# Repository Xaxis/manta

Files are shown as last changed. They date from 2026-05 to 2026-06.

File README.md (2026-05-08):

# MANTA

A wingsuit-extension rigid wing. Pilot wears a fitted wingsuit-derivative
harness with an integrated CFRP spine yoke. Arm-aligned spars hinge from
the spine at the shoulders and brace into position as the pilot spreads
to a flight pose. Telescoping tip extensions snap out from the wrists; a
body-mounted TE spar telescopes spanwise from a hub at the lower back.
Deployable rapidly in flight or on the ground.

This is a real flight vehicle program. Read [`BRIEF.md`](BRIEF.md) before
touching anything else.

**Live project site:** <https://manta-ten.vercel.app>

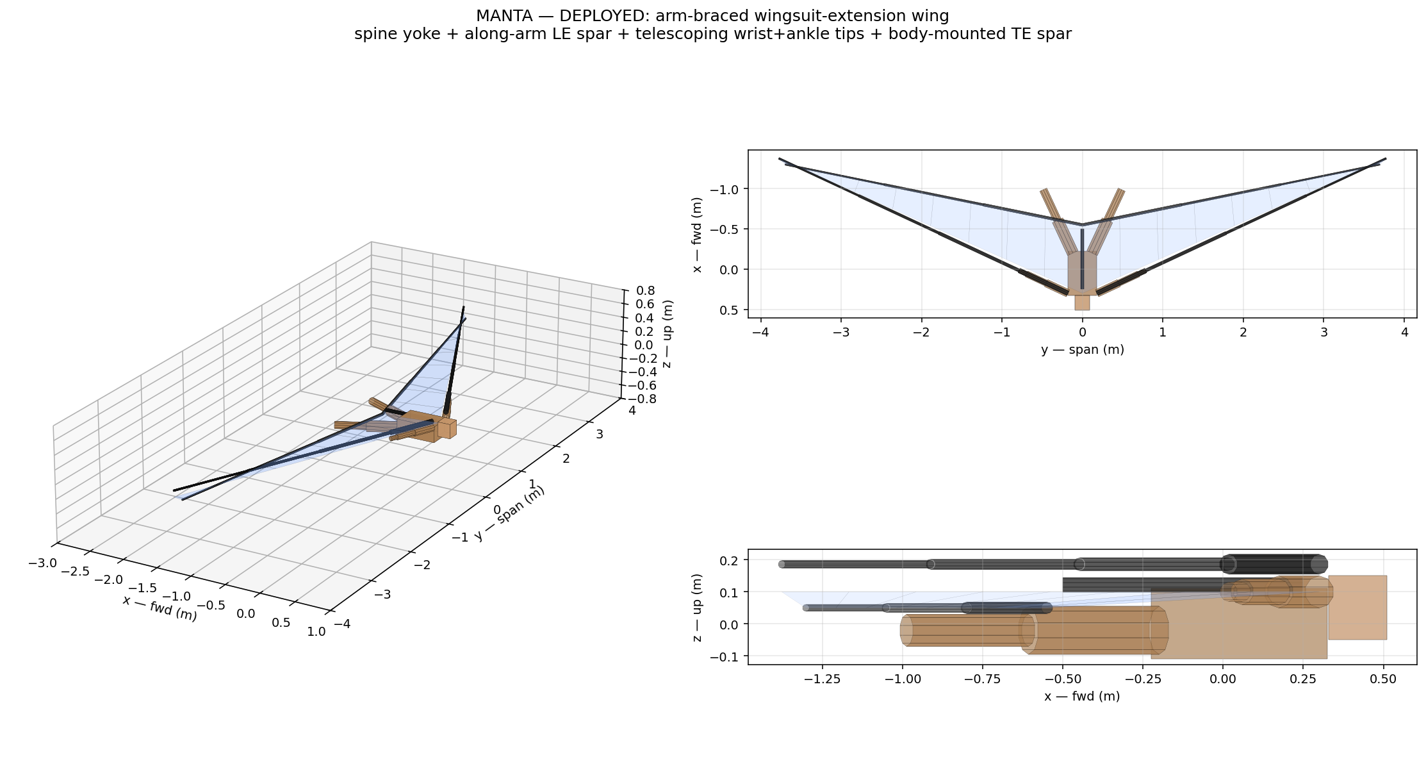
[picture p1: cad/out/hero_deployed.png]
MANTA deployed


## Status

Architecture rebuilt (see [BRIEF v2](BRIEF.md)). The first-cut analyses
across deliverables #1–#6 hold against the corrected architecture; the
wing geometry numbers are independent of how it integrates with the
pilot. CAD and viewer have been rebuilt from scratch around the
arm-braced wingsuit-extension concept.

| BRIEF Deliverable | Doc | Analysis | Tests | Status |
|---|---|---|---|---|
| #1 Aero sizing | [`docs/01`](docs/01-aero-sizing.md) | [`aero/`](analysis/aero/) | 5 ✓ | first-cut |
| #2 Mass budget | [`docs/02`](docs/02-structural-budget.md) | [`struct/mass_budget.py`](analysis/struct/mass_budget.py) | 8 ✓ | first-cut |
| #3 Spar bending | [`docs/02`](docs/02-structural-budget.md) | [`struct/spar_bending.py`](analysis/struct/spar_bending.py) | 8 ✓ | first-cut — load path needs update for arm-braced architecture |
| #4 Deployment sequence | [`docs/03`](docs/03-deployment-sequence.md) | [`deployment/state_machine.py`](analysis/deployment/state_machine.py) | 7 ✓ | first-cut — phases A-B-D added in BRIEF v2 |
| #5 Symmetry budget | [`analysis/deployment/symmetry-budget.md`](analysis/deployment/symmetry-budget.md) | [`deployment/symmetry_budget.py`](analysis/deployment/symmetry_budget.py) | — | first-cut |
| #6 Ground rig spec | [`test/ground/spec.md`](test/ground/spec.md) | — | — | spec drafted — needs update for new kinematics |
| (also) FCS + alpha limiter | [`docs/04`](docs/04-fcs-architecture.md) | [`fcs/`](fcs/) | 7 ✓ | first-cut |
| (also) FMEA | [`safety/fmea.md`](safety/fmea.md) | 11 per-mode files in [`safety/failure-modes/`](safety/failure-modes/) | — | first-cut — pyrotechnic-cutter rows obsolete in BRIEF v2 |
| (also) CAD (corrected) | [`cad/build.py`](cad/build.py) | [`cad/render.py`](cad/render.py) | — | parametric, single source of truth |

> 27 / 27 tests passing. Full suite: `make test`. Site auto-deploys via GitHub Actions on every push touching `site/**`.

## Architecture

Per [`BRIEF.md`](BRIEF.md):

- **Pilot is the fuselage.** Body horizontal in flight, head forward.
- **Spine yoke** (CFRP backbone in the harness) along the back; spar pivots at shoulder + lower-back hub.
- **LE spar** along each arm (shoulder → wrist) with the arm fitted alongside; the spar carries bending load, the arm provides shape and control input.
- **Wrist tip extension** — 3-stage telescoping CFRP from the wrist outward to the wingtip LE.
- **TE spar** — body-mounted spanwise boom from a hub at the lower back, 3-stage telescoping to the wingtip TE. Does not run along the leg (geometric constraint: leg sweep doesn't match TE sweep).
- **Bistable CFRP tape-spring ribs** chordwise between LE and TE spars at multiple span stations.
- **DCF skin** spans LE-to-TE, anchored at body, arms, legs, and tips.
- **Reserve canopy** mounted on the back. After tip-extension retract OR yoke-pivot release, structure folds clear of the reserve cone.
- **Pilot retains wingsuit mode** — if the rigid extensions are fully retracted, the pilot is in a fabric-wingsuit configuration with normal canopy descent capability. That's the architectural fallback.

## Open architecture-amendment findings

1. **V_bg ≈ 16 m/s, not 25 m/s** — wing's natural best-glide is ~16 m/s with the locked planform.
2. **Front spar must grow** to 73 mm OD root, 2.5 mm wall — bending analysis surfaced the original spec failed at 3 g limit. Now relevant to the LE-spar root cross-section.
3. **Active per-side flow modulation** required to close the 10 ms 3-σ symmetry budget.
4. **Architecture is wingsuit-extension, not aircraft-on-back** (BRIEF v2). The prior assumption (separate aircraft on top of a piggyback rig with pyrotechnic spar-root cutters) was wrong; the actual concept is the arm-braced wing. CAD, viewer, and integration are rebuilt around this.

## Reproducibility

```sh
make venv          # one-time setup of .venv
make aero          # planform → Weissinger → trim → glide polar
make struct        # spar bending + mass budget
PYTHONPATH=. .venv/bin/python cad/build.py    # parametric CAD (STL + STEP per part)
PYTHONPATH=. .venv/bin/python cad/render.py   # static iso/top/side hero renders
make test          # full pytest suite
```

Site:

```sh
cd site && bun install && bun run dev    # local preview
cd site && bun run build                  # static build to dist/
```

## Engineering bar

> Would this analysis hold up if a coroner's office asked for it?

If no, it isn't done.

## Where things live

| Path | What's there |
|---|---|
| [`BRIEF.md`](BRIEF.md) | The brief (v2 — wingsuit-extension architecture). |
| [`docs/`](docs/) | Numbered design documents (rationale → aero → structure → deployment → FCS → emergency → test plan → pilot training). |
| [`analysis/`](analysis/) | Quantitative analysis: aero, struct, deployment, flight dynamics. Reproducible via `make`. |
| [`cad/`](cad/) | Single parametric build at `cad/build.py`. Outputs per-part STLs to `cad/out/parts/`. |
| [`fcs/`](fcs/) | Flight control: alpha limiter, SITL simulator, envelope-protection unit tests. |
| [`test/`](test/) | Test article specifications: bench characterization, ground deployment rig, tow article, drop article. |
| [`safety/`](safety/) | FMEA, reserve-parachute compatibility, per-failure-mode write-ups. |
| [`site/`](site/) | Astro + Tailwind + R3F static site. Auto-deploys to manta-ten.vercel.app. |

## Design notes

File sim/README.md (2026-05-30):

# sim — physics + deployment animation pipeline

Two layers, one source of truth for the geometry.

```sh
PYTHONPATH=. .venv/bin/python sim/aero.py              # aero-model closure check
PYTHONPATH=. .venv/bin/python sim/flight_dynamics.py   # trajectory + plot + telemetry
PYTHONPATH=. .venv/bin/python sim/build.py             # MuJoCo kinematics -> animated GLB
PYTHONPATH=. .venv/bin/python sim/build.py --render    # ... + 3 hero stills (Eevee)
```

## 1. Flight physics — `aero.py` + `flight_dynamics.py`

A real six-state longitudinal flight simulation of the whole sequence:
**belly-to-earth freefall → drogue stabilisation → wing deploy → load-limited
pull-out → captured best-glide.**

The aerodynamic coefficients in `aero.py` are derived from the locked planform
(`S = 8.4 m²`, `AR = 6.5`, `e = 0.85`, `CD0 = 0.025`) and are **not** tuned to
hit the BRIEF targets — the targets fall out of the geometry. `aero.py`
asserts the closure on every run:

| Quantity | Model | BRIEF target |
|---|---|---|
| Best-glide speed `V_bg` | **17.0 m/s** | ~16 m/s |
| Max L/D | **13.2** | 10:1 design, 13:1 stretch |
| Stall speed | **12.6 m/s** | < 14 m/s |
| Stowed terminal velocity | **43.9 m/s** | belly freefall ~ |

Coefficients are interpolated stowed→deployed by the deploy progress `p`, so a
single model spans the bluff freefalling body (`p=0`, no lift, vertical
terminal velocity) and the locked wing (`p=1`).

`flight_dynamics.py` integrates the trajectory at 1 ms and closes the pitch
loop with a fly-by-wire longitudinal autopilot (BRIEF #8): a load-factor-limited
flight-path tracker with speed-on-pitch energy regulation and a 12° alpha
limiter. The simulated sequence settles to:

```
V = 17.1 m/s   γ = -4.2°   L/D = 13.7   α = 6.3°   n = 1.0 g
deploy pull-out peak load = 3.1 g   (within the 3 g limit-load spar sizing)
```

Outputs: `out/flight_dynamics.png` (six-panel trace), `out/telemetry.json`
(per-frame series for the web viewer overlay).

## 2. Full mechanical model + deployment animation — `build.py`

`run_simulation()` integrates the deployment **schedule** in MuJoCo (shoulder/
hip yokes spread over Phase A; the wrist + ankle tip booms telescope out over
Phase B). That schedule drives the wing's open fraction.

The vehicle is built from the **resized planform** (BRIEF #5: `S = 6.5 m²`,
`b = 6.3 m`, `AR = 6.1`, `25°` LE sweep, taper `0.4`, `6°` washout — downsized
from 8.4 m²/7.4 m since MANTA lands under reserve) as a **double-surface
cambered wing, tip-to-tip**: an upper deployed skin + a lower wingsuit membrane
meeting at the LE/TE, with the pilot + telescoping spars INSIDE the airfoil — a
ram-air/paraglider-style closed section, continuous across the body and between
the legs.

The pilot is a **fixed-proportion, rigid-size human** (NASA-STD-3000 / ANSUR II
segment lengths) and **never stretches**. Deployment runs forward kinematics
(`_pilot_fk`): the limbs only *rotate* about the shoulder/hip with **constant
bone lengths** (upper arm 0.32 m, forearm 0.27 m, thigh 0.43 m, shank 0.42 m) —
arms angle forward-out toward the LE, legs aft-out forming the **rear/tail**.
The full 7.4 m span beyond the pilot's ~0.76 m wrist reach is provided by the
**3-stage telescoping booms**, not by growing the limbs. Every BRIEF component
is modelled as a named material slot:

| slot | parts |
|---|---|
| `suit` | pilot / harness garment body |
| `cfrp` | spine yoke (box beam), shoulder + hip pivot hubs, LE spar, TE spar, 3-stage telescoping tip booms |
| `skin` | cambered NACA-4412 wing (camber + thickness + washout + billow scallop between ribs) |
| `rib`  | 9 bistable airfoil-profile ribs per side |
| `reserve` | reserve container on the back, above the spine yoke |
| `fcs`  | flight-control bay on the spine |
| `flaperon` | trailing-edge flaperons (deflect down on deploy) |
| `metal` | CO₂ canisters + tip-hub fittings |

The deployable geometry is **one mesh with a fixed topology that is identical on
every frame**; the 60 frames are stored as **morph targets (shape keys)** — a
single `manta.glb` with a real, continuously-interpolated deployment animation
(no opacity crossfades, no per-pose static meshes). Identical-topology morphing
sidesteps skin-weight / bone-roll bookkeeping and guarantees the exact geometry
on every frame, which is what makes the web scrub exact.

## 3. Aero field — surface pressure + streamlines

`build_pressure_object()` and `build_flow_object()` bake an **illustrative**
aerodynamic field onto the deployed wing as two *separate static* GLB objects
(`PRESSURE`, `FLOW`) so they never contaminate the morph mesh's materials:

* **Pressure colormap** — surface Cp on the wing (suction-blue over the leading
  edge, recovering aft), via a thin-airfoil `cp_at()` model **scaled by the real
  Weissinger span-loading** (`analysis/aero/weissinger/out/span_loading.csv` at
  the glide α≈6°).
* **Streamlines** — upwash ahead of the LE → acceleration over the suction peak
  → downwash behind the TE; coloured by local speed `√(1−Cp)`.

This is an **intuition field for the web viewer, NOT a CFD solution** — SU2 /
OpenFOAM is the rigorous follow-up per the BRIEF tool stack. The viewer labels
it as such. The web viewer (`site/src/components/viewer/Viewer.tsx`) plays the
deployment by scrubbing a `THREE.AnimationMixer` clock from the deploy slider,
and its **Flow field** toggle reveals `PRESSURE` + animated `FLOW` streamlines
(a small shader scrolls pulses along each line) over the fully-deployed wing.

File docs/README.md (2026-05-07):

# docs/

Numbered design documents. Read in order.

| # | Document | What it covers |
|---|---|---|
| 00 | [design-rationale](00-design-rationale.md) | Why each locked architecture decision in BRIEF.md was made. The trade studies and rejected alternatives. |
| 01 | [aero-sizing](01-aero-sizing.md) | Planform sizing, airfoil selection, sweep/taper/washout, AVL trim and stability derivatives, L/D verification. |
| 02 | [structural-budget](02-structural-budget.md) | Mass budget, load cases, spar sizing, root-joint design, safety factors. |
| 03 | [deployment-sequence](03-deployment-sequence.md) | Full deployment timeline, sensed handshakes, abort logic. The doc the safety case is built around. |
| 04 | [fcs-architecture](04-fcs-architecture.md) | FCS hardware redundancy, sensor suite, EKF, control laws, envelope protection, mechanical reversion. |
| 05 | [emergency-systems](05-emergency-systems.md) | Spar-root cutters, jettison logic, AAD integration, reserve compatibility, asymmetric-deployment detection. |
| 06 | [test-plan](06-test-plan.md) | Ground rig → tow article → drop article → flight test progression. Gates, instrumentation, success criteria. |

## Conventions

- Every quantitative claim cites its source (analysis file, vendor datasheet, textbook + page).
- Every assumption is called out explicitly, with a justification or a TODO to retire it.
- Every safety-critical claim has a corresponding test in the test plan.
- Diagrams live alongside the doc that references them.
- Treat docs as code — review changes.

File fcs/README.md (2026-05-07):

# fcs/

Flight Control System: firmware, simulation, envelope-protection logic.

**Pairs with:** `docs/04-fcs-architecture.md`, `analysis/flightdynamics/`, and the deployment state machine in `docs/03-deployment-sequence.md`.

## Subdirectories

| Path | Purpose |
|---|---|
| [`firmware/`](firmware/) | PX4 fork (or ArduPilot — pick after architecture review). MANTA-specific modules: deployment state machine, alpha limiter, jettison logic, spar-lock sensor handling. |
| [`sim/`](sim/) | SITL configurations, vehicle model wired to `analysis/flightdynamics/`, scripted mission scenarios for envelope-protection development. |
| [`envelope-protection/`](envelope-protection/) | Standalone development of the alpha limiter and other limiters with unit tests, gain schedules, and HIL fixtures before they land in firmware. |

## Locked from BRIEF

- Redundant Pixhawk-class hardware.
- EKF at 400 Hz.
- Mechanical reversion to direct cable as last-resort backup — the FCS code must not assume it is the only path to the surfaces.
- Alpha limiter is a structural design assumption, treated as required for safe operation.

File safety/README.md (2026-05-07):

# safety/

Safety case artifacts. The bar:

> Would this analysis hold up if a coroner's office asked for it?

If no, it isn't done.

## Contents

| Path | Purpose |
|---|---|
| [`fmea.md`](fmea.md) | Failure mode and effects analysis. Living document — updated as design and test evidence evolves. |
| [`reserve-compat.md`](reserve-compat.md) | Reserve parachute compatibility analysis. The hard-constraint document — the rig must function for canopy flight and landing after wing jettison, and the reserve must deploy clean over the head with no wing-structure occlusion. |
| [`failure-modes/`](failure-modes/) | Per-failure-mode write-ups. Each one: detection, mitigation, response, residual risk, test evidence. |

## Process rules

- Every failure mode listed in `fmea.md` either has a mitigation that closes it to acceptable residual risk, or is a stop-work item until it does.
- Every safety-critical claim cites the test that verifies it — no test, the claim is unverified.
- Failure investigations during test must complete and be reviewed before progression. No "ran it again, it worked."
- Asymmetric deployment is the dominant unrecoverable failure mode (BRIEF). Its file under `failure-modes/` is the one that gets the most attention.

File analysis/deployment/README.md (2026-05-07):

# analysis/deployment/

Deployment dynamics. Pairs with `docs/03-deployment-sequence.md`.

## Tools

- 0-D / 1-D pneumatics for CO2 cartridge → manifold → actuator energy delivery.
- Python ODE models for tape-spring rib snap-through dynamics.
- High-speed video (frame extraction) once the ground rig is built — feeds parameter ID back into the models.

## Expected layout (to be populated)

```
deployment/
├── pneumatics/             # CO2 blowdown, manifold balance, valve opening
├── tape-spring/            # bistable shell snap-through energy + timing
├── timing/                 # composite end-to-end timeline + per-stage budgets
├── symmetry-budget.md      # deliverable #5
├── drogue/                 # ringslot reefed inflation, snatch loads
└── README.md
```

## Critical: symmetry budget (deliverable #5)

`symmetry-budget.md` quantifies left-right deployment timing variance, contributors include (non-exhaustive):

- CO2 cartridge fill mass tolerance and temperature dependence
- Valve opening time-to-flow variance
- Manifold flow-impedance balance
- Spar friction (telescoping stages, with water/ice ingress)
- Tape-spring snap-through dispersion
- Sensor-trigger threshold variance

**Hard gate:** total left-right variance must close to under **10 ms 3-σ** across the operational envelope. If the budget does not close, architecture decision #5 in BRIEF is reopened.

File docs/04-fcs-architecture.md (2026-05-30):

# 04 — FCS Architecture

> **⚠ Resized planform — FCS is now MORE load-bearing.** The wing was downsized
> to **6.5 m² / 6.3 m, AR 6.1, 7° washout** (BRIEF findings #5/#6) and the
> flight-dynamics were re-run. The binding (CG-based) **static margin is ~2.7 %
> MAC** (a ~3 cm aft pilot shift takes it neutral) and **Dutch-roll ζ dropped to
> 0.17** (was 0.29). Consequence: the **alpha-limiter and the artificial yaw
> damper are now MANDATORY flight-safety items**, not optional. `analysis/
> flightdynamics/out/` + `fcs/sim/out/` are regenerated for the new planform.

**Status:** First-cut closed. Limiter prototype, longitudinal dynamics
analysis, and closed-loop characterization are runnable. Outstanding work
is the lateral-directional axis and the actual hardware/firmware build
(PX4 fork or ArduPilot equivalent).

## Locked from BRIEF

- Redundant Pixhawk-class FCS.
- EKF at 400 Hz.
- MEMS IMUs.
- Flaperons (servo-driven, brushless waterproof) on the outer trailing
  edge each side.
- **Alpha limiter is a structural design assumption** — not a feature, an
  invariant the structural sizing depends on.
- Mechanical reversion to direct cable as last-resort backup.

## Why the alpha limiter is load-bearing

Two findings from the upstream analyses converge here:

1. **Static margin is tight.** At design CL the wing has 5.4 % MAC margin
   (top-of-BRIEF-range washout). At higher CL (slow flight, near stall)
   it drops below 4 %. ([`docs/02`](02-structural-budget.md), [`analysis/aero/trim/`](../analysis/aero/trim/))

2. **Pilot motion eats most of the margin.** The pilot is 79 % of the
   vehicle mass and not rigid. A 50 mm head/torso CG shift produces a
   ±3.26 % MAC vehicle-CG shift — comparable to the entire static margin.
   At the trim CG, short-period damping ζ = 0.97 (heavily damped). At a
   50 mm aft pilot shift, the wing goes neutrally stable; at larger
   shifts, divergent. ([`analysis/flightdynamics/longitudinal.py`](../analysis/flightdynamics/longitudinal.py))

The alpha limiter, combined with body-rate damping in the inner loop, is
the only thing that prevents departure during a worst-case posture
perturbation at high CL. Loss of the limiter is a **hazardous failure
mode**, listed in the FMEA.

## Topology

```
                                     ┌──── pitot/static (×2) ────┐
                                     │                            │
                                     │     AoA vane (×1)          │
                                     │     IMU triplex            │
                                     │     spar-lock GPIO (×6)    │
                                     │     skin-tension cells (×4)│
                                     │     drogue load cell       │
                                     │                            ▼
                                     │                       ┌─────────────┐
                                     │                       │ EKF (400Hz) │
                                     │                       └─────┬───────┘
   pilot stick / abort handle        │                              │
   AAD trigger (FCS-bypassed)        │                              ▼
            │                        │      ┌─────────────────────────────────┐
            │                        ├─────►│ Outer loop: trim, glide, alpha  │
            │                        │      │  hold + ALPHA LIMITER           │
            │                        │      └─────────────────┬────────────────┘
            │                        │                         ▼
            │                        │        ┌──────────────────────────────┐
            │                        ├───────►│ Inner loop: pitch-rate,      │
            │                        │        │  roll-rate, yaw-rate damping │
            │                        │        └─────────────┬────────────────┘
            ▼                        │                       ▼
     ┌──────────────────────────┐    │             ┌────────────────────┐
     │ Deployment state machine │────┘             │ Mixer + servo cmd  │
     │ + jettison interface     │                  └─────────┬──────────┘
     └──────────────────────────┘                            ▼
                                                  ┌──────────────────────┐
                                                  │ Flaperon servos (×4) │
                                                  └──────────────────────┘
```

## Hardware redundancy

- **Two Pixhawk-class FCS units** (FCS-A and FCS-B), running cross-checked
  EKFs. Either can fly the vehicle alone; swap is automatic on health failure.
- **Independent power rails** for FCS-A and FCS-B; a third independent rail
  for the mechanical-reversion logic + cutter firing circuit so jettison
  remains possible if both FCS units lose power.
- **Standalone aux IMU** wired to FCS-B (and physically separated from the
  FCS-A IMUs) — provides a third attitude solution for cross-check.
- **AAD signal** wired directly to the cutter firing circuit, bypassing
  both FCS units. (See `safety/failure-modes/aad-fault.md`.)
- **Mechanical reversion**: direct cable from a stick-style pitch input to
  the flaperons. Operable with FCS fully unpowered; pilot reach geometry
  verified in `cad/harness/`.

## Sensor suite

| Sensor | Count | Purpose | Notes |
|---|---|---|---|
| 9-DoF IMU | 3 (FCS-A, FCS-B, aux) | attitude, body rates, accel | Cross-checked via EKF |
| Magnetometer | 2 | heading | Magnetic deviations from skydiving rig metalwork need calibration on every aircraft |
| GNSS | 2 | position, ground speed | Degraded-mode ground speed if pitot fails |
| Pitot-static | 2 | airspeed, altitude rate | Boom location TBD; must avoid wing wake during deploy |
| AoA vane | 1 | direct α | Single-channel; loss → degraded-mode α estimate from trim equation |
| Spar-lock micro | 6 | deployment confirmation | ≤ 1 ms latency requirement (see `docs/03`) |
| Skin tension load cells | 4 | deploy diagnostic | Advisory only — does not gate deployment |
| Drogue load cell | 1 | deployment gate | Cross-checked vs. accel signature |

## Control laws

### Outer loop — alpha limiter (the central piece)

Implementation: [`fcs/envelope_protection/alpha_limiter.py`](../fcs/envelope_protection/alpha_limiter.py).

Limit schedule:

| V (m/s) | α_limit (°) | α_limit, sensor degraded (°) |
|---|---|---|
| 10 | 7.86 | 6.36 |
| 14 | 9.00 | 7.50 |
| 16 (V_bg) | 9.00 | 7.50 |
| 20 (cruise) | 9.00 | 7.50 |
| 25 | 9.00 | 7.50 |
| 30 | 9.00 | 7.50 |
| 35 | 9.50 | 8.00 |
| 40 | 10.00 | 8.50 |

Stall α is 11.5° (analytic polar). Margin 2.5° in the cruise band, +1.5° additional in degraded mode (sensor failure).

Behavior:
- Pilot stick → α_pilot_cmd
- α_cmd = min(α_pilot_cmd, α_limit(V, sensor_state))
- saturated flag → inner loop integrator anti-windup
- degraded flag → α estimate from trim equation: α = α₀ + (1/CL_α) · (m·g)/(½·ρ·V²·S)

Validated by 7 unit tests in [`fcs/envelope_protection/tests/`](../fcs/envelope_protection/tests/).

### Inner loop — pitch / roll / yaw rate damping

PI on α error + Kq on pitch rate (longitudinal). Same structure for the
lateral axes. Anti-windup hooks via the α-saturated flag from the outer
loop. Tunings are placeholders pending high-fidelity 6DOF in SITL.

### Trim hold

Slow (~1 Hz) outer loop adjusts α_cmd to maintain a target airspeed. Pilot
override available; otherwise the FCS holds best-glide trim by default.

## Closed-loop characterization

Three scenarios in [`fcs/sim/closed_loop.py`](../fcs/sim/closed_loop.py):

| Scenario | What it shows |
|---|---|
| `pilot_overcmd` | Pilot demands α = 12° at cruise. Limiter clamps at α_limit ≈ 9° for 83 % of the run; anti-windup holds; α is held at the model's hard ceiling, not exceeded. |
| `cg_shift_50mm` | 50 mm aft CG shift (worst-credible posture change). With no other disturbance the trim point holds — the dynamics rebuild against the shifted A matrix do not destabilize. |
| `combined_overcmd_cg` | Both at once. Limiter still saturates correctly. |

**Caveats made explicit in the simulator docstring:** the plant is a
linearized state-space about trim. Outside ±20 % from trim it does not
represent the real wing. **Gust ingestion is deferred to a non-linear 6DOF
simulator** that's out of scope for first-cut. The closed-loop sim is a
limiter-logic characterization tool, not a flight-validation simulator.

## Sensor-fault modes

| Failed sensor | FCS response | Vehicle behavior |
|---|---|---|
| AoA vane | Degraded-mode α estimate from trim equation; α-limit margin widens by 1.5° | Flyable; pilot informed; reduced authority near stall |
| One pitot-static channel | Use the other; cross-check against GNSS ground speed | No degradation if both pitots agree pre-failure |
| Both pitot-static channels | Use GNSS-derived ground speed as airspeed proxy (degraded — wind error); widen α-limit margin further | Flyable in calm air; risky in gusty conditions; recommend reserve |
| One IMU | EKF flags + voting drops bad channel | No degradation |
| Two IMUs | Single remaining IMU is authoritative | Substantially degraded; consider deploy-completed reserve |
| Spar-lock sensor | If pre-deploy: jettison if any-lock-fail timeout. If post-deploy: advisory only | See `docs/03` |
| FCS-A failure | FCS-B takes over; transition transient < 100 ms | Functional with full authority |
| FCS-A + FCS-B failure | Mechanical reversion (manual cable to flaperons) | Substantially degraded; pilot must hand-fly with no envelope protection — α-limiter loss is a **hazardous** mode (FMEA `FM-FCS-001`) |

## Mechanical reversion

- Direct mechanical linkage from pilot stick to a single set of flaperon
  surfaces (the *outer* flaperon segment per side; inner segment locked
  out in reversion mode for simplicity).
- Engaged automatically when both FCS units flag fault, or manually from
  a guarded cockpit switch.
- Pilot has no envelope protection in this mode. Recovery procedure is
  immediate jettison + reserve at any altitude > 200 m AGL where
  jettison is still safe.

## To-build (firmware)

The architecture above is implementable on PX4 or ArduPilot. Both have
existing infrastructure for IMUs, EKF, SITL, mixers, and servos. Choice
of which to fork is deferred to firmware-team selection; the limiter and
state-machine modules in [`fcs/`](../fcs/) are framework-agnostic Python
prototypes that translate cleanly to either.

## Lateral-directional dynamics

Implementation: [`analysis/flightdynamics/lateral.py`](../analysis/flightdynamics/lateral.py).

First-cut estimates of the stability derivatives (Roskam Vol. I tables for
swept tailless wing, no vertical tail) feed a 4-state lateral state-space
[β, p, r, φ]. Headline findings across the operational speed range:

| Mode | V = 16 m/s (V_bg) | V = 20 m/s (cruise) | V = 25 m/s | Verdict |
|---|---|---|---|---|
| Dutch roll | ω_n = 2.40, ζ = +0.29 | ω_n = 2.35, ζ = +0.26 | ω_n = 2.55, ζ = +0.27 | **Level 2** (acceptable but light) |
| Roll mode | τ = 0.064 s | τ = 0.049 s | τ = 0.039 s | crisp |
| Spiral mode | **DIVERGENT, T₂ = 15 s** | **DIVERGENT, T₂ = 80 s** | convergent, τ = 80 s | unstable below cruise |

Two consequences for the FCS architecture:

1. **Yaw damper required.** Dutch roll at 0.26 ζ is acceptable for a
   gliding aircraft but right at the threshold of pilot-irritating;
   handling qualities improve markedly above 0.40. The FCS adds an
   artificial Cn_r contribution by feeding sensed yaw rate into
   differential flaperon (right-flaperon-down + left-flaperon-up
   produces a yaw moment via wing drag asymmetry). Tuning is a
   placeholder until 6DOF SITL is in place.

2. **Spiral mode autopilot or persistent pilot attention.** At V_bg the
   spiral doubles in 15 s — pilot can easily fly through this but
   cannot leave the controls. The FCS should provide bank-hold
   functionality (close a φ loop with the ailerons) for normal
   cruise. Loss of this is **major** (Cooper-Harper drift), not
   hazardous — pilot can still fly.

These are first-cut numbers — Cn_β and Cn_r in particular for a tailless
wing are sensitive to fuselage / harness / pilot-body shadowing of the
sweep contribution, which is exactly the kind of effect a vortex-lattice
code (AVL) captures and our hand-calc does not. Validate with AVL before
treating as load-bearing.

## Open issues

1. **AVL validation of lateral derivatives.** Cn_β especially — if AVL
   reports a smaller value than our 0.020 placeholder, dutch-roll damping
   could drop into Level 3 territory and the yaw damper becomes
   *mandatory* not *recommended*.
2. **Servo selection.** Need a waterproof brushless servo with
   ≥ 100 deg/s slew, ≥ 5 N·m holding torque, and < 5 ms control-input
   latency. Vendor survey pending.
3. **Pilot input device.** Yoke? Body-tilt sensor? Stick? Constrained by
   the deployed-wing pilot ergonomics. Owns `cad/harness/`.
4. **Anti-windup tuning.** The current PI inner loop is illustrative; real
   gains come from high-fidelity 6DOF simulation in PX4 SITL.
5. **EKF tuning.** Sensor-fault transition behavior, particularly the
   pitot/GNSS handoff during gusts, needs simulation work.
6. **Hardware-in-the-loop test fixture.** Should sit alongside the ground
   deployment rig (`test/ground/`) so the FCS exercises real spar-lock
   GPIO and real cutter-firing circuits during integration.

## Reproducibility

```sh
PYTHONPATH=. .venv/bin/python -m analysis.flightdynamics.longitudinal
PYTHONPATH=. .venv/bin/python -m fcs.envelope_protection.alpha_limiter
PYTHONPATH=. .venv/bin/python -m fcs.sim.closed_loop
PYTHONPATH=. .venv/bin/python -m pytest fcs/ -v
```

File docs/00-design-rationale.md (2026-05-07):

# 00 — Design Rationale

**Status:** stub — to be filled before deliverable #1 closes.

## Purpose

This document captures the *why* behind each locked architecture decision in `BRIEF.md`. For each decision: the alternatives that were considered, the criteria, and the evidence that drove the choice. When new evidence emerges that challenges a locked decision, this is where the re-evaluation lives.

## Decisions to document

For each of the following, write up: alternatives considered, decision criteria, decision, and what would force a revisit.

1. Two-spar telescoping CFRP wing (vs. single-spar, vs. inflatable, vs. jointed-folding).
2. 9 ribs/side bistable tape-spring (vs. articulated rigid ribs, vs. inflatable ribs, vs. fewer ribs + stiffer skin).
3. DCF skin (vs. mylar, vs. coated nylon, vs. molded composite shell).
4. 25° sweep / 0.4 taper / 4-6° washout planform.
5. Pneumatic CO2 deployment (vs. spring-loaded, vs. pyrotechnic, vs. powered/electric).
6. Drogue-first sequence (vs. direct-deploy at terminal).
7. Pixhawk-class redundant FCS with mechanical reversion (vs. single FCS, vs. fully mechanical).
8. Wing-on-rig architecture with pyrotechnic jettison (vs. integrated rig, vs. dropaway design).

## Format per decision

```
### [Decision name]
**Locked answer:** ...
**Alternatives considered:** ...
**Selection criteria (in priority order):** ...
**Evidence / analysis:** ... (cite analysis files, references)
**What would force a revisit:** ...
**Open questions:** ...
```

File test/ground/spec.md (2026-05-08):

# Ground deployment rig — specification

**Status:** Specification draft. Build is gated on adopting Option B from
the symmetry budget (see `analysis/deployment/symmetry-budget.md`) and
finalizing the cutter / fitting interface (`cad/jettison/`).

This is the **first piece of MANTA hardware to actually build** per BRIEF.
It exists to:

1. Measure each contributor in the deployment-symmetry budget.
2. Demonstrate sub-10 ms 3-σ symmetric deployment with the chosen architecture.
3. Run the **200-cycle reliability gate** that gates progression to flight-relevant test articles.

The rig is *intentionally not flightworthy*. Wing assembly is held in a
fixture; there are no flight loads, no dynamic pressure, no pilot.
The rig isolates and measures the deployment kinematics and timing.

## Architecture

```
                    ┌─────────────────────────────────────────────┐
                    │    Stiff steel-tube test stand               │
                    │                                              │
                    │    ┌─────────────────────────────────┐       │
                    │    │  Wing assembly (front + rear    │       │
                    │    │  spars, 18 ribs, full skin)     │       │
                    │    │  fixed at root mount points     │       │
                    │    └─────────────────────────────────┘       │
                    │                                              │
                    │    Environmental enclosure (separate):       │
                    │      thermal chamber                         │
                    │      humidity / spray rig                    │
                    │      ice conditioning bath                   │
                    └─────────────────────────────────────────────┘

   Instrumentation chain:
     spar-lock microswitches  ──►  GPIO (1 kHz)
     valve actuation feedback ──►  ADC (10 kHz)
     manifold pressure (per port) ──► ADC (10 kHz)
     CO2 bottle T + P  ──────►  serial probe
     skin tension load cells (4) ──► ADC (1 kHz)
     ambient T, RH ──────────► serial probe
     high-speed video (≥ 1000 fps, both wings, two angles) ──► storage
```

### Mechanical fixture

- 80/20 extrusion frame, ~2 m × 4 m footprint, leveling feet.
- Wing root fixture: bolts to a sub-frame matching the harness mount pattern
  (BRIEF "wing harness sits on top of the piggyback rig"). Sub-frame is
  rigid enough to prevent root spar motion during deploy (>10 kN root
  reaction over ~50 ms — sized in `analysis/struct/spar_bending.py`).
- Wing tips: free. The tips swing through ~3.7 m arcs during deploy and
  must clear the test floor and walls. Side clearance ≥ 4.5 m total to
  the nearest obstruction.
- Restow station: tooling fixture that re-stows the wing into its packed
  configuration between cycles. Designed for ≤ 5 minute restow cycle so
  that 200 cycles fits in a working week.

### Environmental conditioning

Per BRIEF: cold + wet are the binding cases. The rig must condition the
wing assembly to the operational envelope:

| Condition | Temperature | Humidity / wet state | Soak time | Cycles |
|---|---|---|---|---|
| Hot/dry | +50 °C | < 20 % RH | 4 h | 25 |
| Hot/humid | +35 °C | 95 % RH | 4 h | 25 |
| Nominal | +20 °C | 50 % RH | — | 50 |
| Cold | −10 °C | dry | 4 h | 25 |
| Cold/wet | −5 °C | spray-soaked then drained | 4 h | 25 |
| Cold/iced | −5 °C | spray-soaked, then frozen | 6 h | 25 |
| Re-test in nominal | +20 °C | 50 % RH | — | 25 |
| **Total** | | | | **200** |

The conditioning enclosure can be a separate walk-in chamber; the
deployment fixture is on a roll-in cart.

## Instrumentation

### Per-side stage-lock sensors

Six microswitches per wing assembly (3 stages × 2 sides) — one at each
telescoping joint, latching when the inner stage is fully extended and the
locking pin engages. Required:

- Latency from physical close to FCS GPIO read: **≤ 1 ms** (drives microswitch
  selection — many parts have 5–10 ms software-debounce by default; we want
  hardware contact only).
- Two independent contacts per switch, cross-checked.
- Voltage levels and connector compatible with the FCS GPIO bus.

Verification of latency is a bench step in itself: drop test of a switch
into a calibrated impactor, capture both the impact event (accelerometer)
and the switch close (GPIO) at 100 kHz, verify ≤ 1 ms.

### Manifold pressure sensors

Pressure transducer in each port of the CO2 manifold (2 sides + supply line):
- Range 0–100 bar
- 10 kHz sample rate
- Time-aligned to all other channels

These are the primary diagnostic for manifold balance issues and CO2
cartridge variance.

### Skin tension load cells

4 load cells (2 per side) at the chord stations specified in
`docs/02-structural-budget.md`. Used for:
- Skin attachment and tension diagnostic during deploy
- Detection of skin failure or asymmetric tension (advisory only)

Range 0–500 N each, 1 kHz sample rate.

### Drogue load cell

Not strictly needed on the ground rig (no drogue sequence here), but the
mounting interface should be present so the same fixture can support
later drop-test article verification.

### High-speed video

Two cameras at ≥ 1000 fps, each with a clean view of one wing's full deploy
trajectory. Synchronized to the DAQ (LED tally light or external trigger
on every frame). Used for:
- Per-rib unfurl time measurement (frame extraction)
- Visual confirmation of skin behavior
- Failure-mode diagnostics when something breaks

A single fixed studio-style lighting setup is acceptable; outdoor / sun
not required.

### Ambient + assembly conditioning probes

- Ambient T / RH at fixture
- T probe in the wing assembly itself (between ribs, mid-span)
- T + P at each CO2 cartridge

## Data acquisition

- Centralized DAQ with hardware-time alignment across all channels.
- Per-cycle, write a single HDF5 file with all channels indexed by cycle
  number, environmental condition, and timestamp.
- File naming: `cycle_{NNN}_{condition}.h5`.
- Retention: every cycle, no exceptions.

## Test cards

A single test card is one trial: condition → cycle → data file. The card
captures:

- Condition label
- Wing assembly serial / build number
- Restow notes (any anomalies during pack)
- Environmental probe values immediately before fire
- CO2 cartridge serial(s) and pre-fire mass / temperature
- Operator
- Timestamp
- Pass / fail per channel
- Free-text observation

200 cards per gate run. Card template lives in `test/ground/cards/`.

## Pass / fail criteria — the 200-cycle gate

Per BRIEF:
> Do not move to flight-relevant test articles until the ground deployment
> rig has demonstrated reliable, symmetric, sensed deployment over the full
> thermal and humidity envelope, in at least 200 cycles without intervention.

Concretely:

1. **Symmetry:** measured |Δt_LR| from the spar-lock channels, across all
   200 cycles, has 3-σ ≤ 10 ms. (See `analysis/deployment/symmetry-budget.md`
   for what makes this realistic.)
2. **Lock confirmation:** all 6 lock channels confirm within 50 ms of cmd
   on every cycle. No "no-lock" events.
3. **Skin tension:** load cells reach > 80 % of nominal within 200 ms on
   every cycle.
4. **No intervention:** no operator touched the wing during a cycle other
   than restow between cycles. No fixed/repaired components mid-run; if
   anything breaks, the cycle stops, the failure is investigated and
   written up, and the count restarts after the fix.
5. **Cross-condition:** at least 25 cycles in each of the conditions in
   the table above.

## Failure-investigation protocol

When something breaks:

1. Stop, do not attempt a recovery deploy or a "let's see if it works
   the next time".
2. Capture state: photograph fixture, save the cycle's HDF5 file, save the
   high-speed video, note operator's last actions, note environmental probe
   values.
3. Open a failure-investigation entry in `safety/failure-modes/`.
4. Write up: what happened, what data shows, root cause, remedy.
5. Verify remedy: 5 cycles of the same condition before resuming the gate
   sequence.
6. Restart the 200-cycle count after the fix is verified — no "credit" for
   pre-fix cycles.

This is the BRIEF rule: "no 'ran it again, it worked' closures."

## Hardware deliverables (in build order)

1. Steel-tube fixture frame + sub-frame.
2. Restow station tooling.
3. Lock sensor selection + latency-verified bench test.
4. Manifold pressure transducer integration.
5. Skin-tension load cell integration.
6. DAQ + storage chain.
7. High-speed video setup + sync.
8. Environmental chamber rental / build, plus spray rig and ice bath.
9. First wing assembly built specifically for the rig (designated R-1).
10. Test cards printed, run procedure rehearsed dry.
11. First condition run (nominal × 50 cycles) for sensor and procedure
    debugging — *not* counted toward the gate.
12. Gate run (200 cycles).

## What's deferred

- Pyrotechnic cutter firings on the ground rig: only after the deploy gate
  is closed, in a separate test campaign at a range with appropriate
  controls. Cutter firings are destructive to the root fittings, so each
  is a single-shot.
- Drogue sequence: lives in the drop article (`test/drop/`), not here.
- Flight loads: lives in tow article (`test/tow/`), not here.

## Reproducibility / cost note

The rig is fixture and instrumentation only — no flight hardware in it
that isn't a serviceable wing assembly. Estimated build cost is dominated
by the environmental chamber (rent vs. build trade) and the high-speed
video. Both are reusable for downstream test articles. Order-of-magnitude
$100k – $250k depending on chamber choice. Time-to-first-fire: 3–6 months
from spec lock.

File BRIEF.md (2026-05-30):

# Project MANTA

## What this is

A **deployable rigid-wing extension to a wingsuit-style flight system**.
The pilot wears a fitted wingsuit-derivative garment with an integrated
deployable structure: a CFRP spine yoke mounted on the back, with
arm-aligned and leg-aligned spars that brace into position as the pilot
spreads to a flight pose. Telescoping tip extensions from the wrists and
ankles complete the wingspan. Deployable rapidly — in flight from
freefall posture, or on the ground from a packed configuration.

This is a real flight vehicle development program disguised as a piece
of sporting goods. Treat it as such.

## Architecture (locked unless evidence forces a change)

1. **Pilot is the fuselage.** Pilot wears a fitted, fabric-skinned
   harness garment (wingsuit-derivative) with an integrated CFRP spine
   yoke along the back. Pilot's body forms the central wing chord.

2. **Two-spar, four-arm-braced structure.** Per side:
   - **Leading-edge (LE) spar:** rigid CFRP boom, hinged at the spine
     yoke at the shoulder. Runs along the pilot's arm (underside,
     bonded to the harness sleeve) from shoulder to wrist. The pilot's
     arm fits alongside the spar; the spar carries the bending load,
     the arm provides the aerodynamic shape and control input.
   - **Trailing-edge (TE) spar:** mirror geometry along the pilot's
     leg, hinged at a hip yoke, from hip to ankle.
   - **Wrist tip extension:** 3-stage telescoping CFRP boom from the
     wrist hub outward to the wingtip leading edge. Pneumatic CO₂
     extension.
   - **Ankle tip extension:** mirror, from ankle hub to wingtip
     trailing edge. Pneumatic CO₂ extension, sequenced with the wrist
     extension for symmetric deploy.

3. **Bistable CFRP tape-spring ribs.** 9 per side, span chordwise
   between LE and TE spars. Coiled at the spar in stowed; snap-deploy
   as the spars reach their locked positions. Passive — no power
   required.

4. **DCF skin.** ~50 g/m², bonded to ribs and to the harness body
   panels, tensioned by full deployment of the structure.

5. **Wing planform — resized (finding #5).** S = 6.5 m², b = 6.3 m,
   AR = 6.1, 25° LE sweep, taper ratio 0.4, 7° tip washout. Downsized
   from the original 8.4 m² / 7.4 m: because MANTA lands under a reserve
   canopy (not on the wing), a low stall speed is not required, which
   frees the wing to shrink for a far more feasible ~2.4 m telescoping
   boom while holding the glide target (L/D ≈ 11.6 at V_bg ≈ 18 m/s).
   Source of truth: `analysis/aero/planform/geometry.py`.

6. **Deployment sequence (~0.6 s end-to-end):**
   - **Phase A (~0.3 s):** pilot extends arms and legs outward from
     stowed posture. Pneumatic shoulder/hip yokes assist and lock the
     spars at the deployed sweep angle.
   - **Phase B (~0.1 s):** CO₂ fires; telescoping tip extensions snap
     out from wrist and ankle hubs simultaneously. Sequenced through
     a single valve per side for symmetry (active modulation per the
     symmetry-budget analysis).
   - **Phase C (~0.05 s):** bistable ribs snap to open shape as the
     extended spars pass them.
   - **Phase D (passive):** skin tensions across the deployed
     structure; FCS captures trimmed glide.

7. **In-flight deployability.** Because the deployment is the pilot
   spreading from a tucked posture to spread-eagle, it works equally
   well from a stable freefall posture (no drogue stabilization
   needed — spread-eagle freefall is self-stable) or from the ground
   (e.g., for cliff-launch or aircraft-floor pre-deploy).

8. **Fly-by-wire control.** Redundant Pixhawk-class FCS, EKF at 400 Hz,
   MEMS IMUs. Flaperons (servo-driven, brushless waterproof) on the
   trailing-edge tip extensions. Pilot also has body-control authority
   via shoulder/hip rotation against the locked spar — a hybrid
   control path that maps directly to wingsuit pilot intuition. The
   alpha limiter remains a structural design assumption.

9. **Reserve canopy compatibility.** Reserve container is on the
   pilot's back, ABOVE the spine yoke (where the FCS bay sits in
   front of the reserve PC launch path). After tip-extension retract
   OR yoke release (the yoke spar pivots disengage from the spine on
   command), the rigid structure folds clear of the reserve cone.
   No pyrotechnic spar-root cutters required — disengagement is
   mechanical, latched, and reversible.

10. **Pilot fully retains wingsuit mode.** If the rigid structure is
    fully retracted (tip extensions in, yokes folded), the pilot is
    in a fabric-wingsuit configuration and can fly under fabric-wing
    control to a normal canopy descent. This is the architectural
    fallback.

## Performance targets

- Glide ratio: 10:1 design target, ~12:1 stretch (vs. 3:1 wingsuit, 16:1 hang glider)
- Best-glide airspeed: ~18 m/s (per the glide-polar analysis, resized planform)
- Stall speed: ~15-16 m/s (relaxed — landing is under reserve canopy, not the wing)
- Pilot mass envelope: 70-95 kg
- Wing area: 6.5 m²
- Span: 6.3 m deployed
- Aspect ratio: 6.1
- Wing loading: ~16.6 kg/m² (163 N/m²; structurally-correct mass per finding #2)
- Wing system mass budget: ~16.5 kg (per the bending-sized spar — see
  finding #2)
- Stowed package thickness (off body): TBD per the new architecture;
  the BRIEF v1 target of 150 mm was for a wing-on-rig-stack design that
  did not work — the arm-braced architecture is much thinner because
  the structure runs along the arms/legs rather than on top of the
  pilot's back.

## Open architecture-amendment findings (from the analysis)

These came out of deliverables #1–#6 + the architecture rebuild:

1. **V_bg ≈ 18 m/s, not 25 m/s** — best-glide is ~18 m/s on the
   resized 6.5 m² wing (was ~16 on the 8.4 m²); superseded by
   finding #5 (analysis/aero/lift_drag/).
2. **Front spar must grow** to 67 mm OD root, 2.5 mm wall (was
   40 mm/2 mm) — bending analysis. (73 mm on the old 8.4 m² wing;
   the resized shorter span drops it to 67 mm — finding #6.)
3. **Active per-side flow modulation** (rather than passive matched-
   impedance manifold) is required to close the 10 ms 3-σ symmetry
   budget.
4. **The fundamental architecture was wrong** — the prior BRIEF
   described an aircraft-on-pilot's-back configuration with
   pyrotechnic root cutters, a stowed-package-on-rig stack, and a
   wing planform floating above the pilot. The CORRECT concept is the
   arm-braced wingsuit-extension architecture defined above. This
   amendment supersedes architecture decisions in BRIEF v1.
6. **The 6.5 m²/6.3 m resize (finding #5) costs stability — partly
   mitigated.** Re-running struct + flight-dynamics for the smaller
   wing: Dutch-roll damping drops to **ζ ≈ 0.17** (was 0.29), the
   spiral diverges faster, and the **binding (CG-based) static margin
   is ~2.7 % MAC** — tight, and a ~3 cm aft pilot CG shift takes it
   neutral. **Action taken:** washout raised 6°→7° (geometry.py); this
   restores the *trim* static margin to **5.6 %** and keeps a healthy
   ~10° tip-stall margin, but the *dynamic* CG-based margin (~2.7 %) is
   washout-independent — genuinely recovering it needs a CG shift (wing
   aft / mass fwd). The design is fly-by-wire by intent, so ~2.7 % is
   FCS-managed: the **alpha-limiter and yaw damper are now mandatory
   flight-safety items**, not optional. Spar got lighter (67 mm root vs
   73, shorter span → less moment). Resize upside unchanged: 2.4 m boom
   (was 2.9), L/D 11.6. **Open:** accept FCS-managed margin (current) or
   revisit wing size / CG for more passive stability.

## First deliverables (revised priority)

Build in this order. Do not skip ahead.

1. `cad/build.py` — single parametric build of the integrated
   architecture: pilot humanoid, spine yoke, arm/leg spars,
   telescoping tips, ribs, skin. Driven by `deploy_state ∈ [0,1]`.
2. `cad/render.py` — multi-view static render + animation frames.
3. `site/src/components/viewer/Viewer.tsx` — interactive 3D viewer
   with bone-hierarchy animation matching the deployment sequence.
4. `analysis/struct/spar_bending.py` — load case update for the
   arm-aligned spar (cantilever from the shoulder/hip yoke, not from
   a sub-frame on a rig). Magnitude similar but the load path is
   different.
5. `analysis/deployment/state_machine.py` — phases A-B-C-D timing per
   the new sequence.
6. `test/ground/spec.md` — ground rig spec updated for the new
   deployment kinematics (arm-spread, tip-extend, rib-snap).

## Tools and software stack

- Aero: AVL (vortex lattice), XFOIL (airfoil), OpenVSP (geometry).
  Optional later: SU2 or OpenFOAM CFD.
- Structural: hand calcs in Python, FEA via CalculiX or FreeCAD FEM
  workbench for the spine yoke and shoulder/hip pivots.
- CAD: CadQuery (FreeCAD-importable STEP) parametric, single source
  of truth at `cad/build.py`.
- FCS: PX4 fork (or ArduPilot reference). SITL for envelope-protection
  development.
- Site: Astro + Tailwind + R3F (Three.js) for the live 3D viewer.

## Engineering culture

This project kills people if done sloppily. Every analysis is
reviewable. Every assumption is cited. Every safety-critical claim
has a test that backs it. No vibes-based engineering. The bar is:
would this analysis hold up if a coroner's office asked for it.

## Out of scope (for now)

- Powered variants. v1 is unpowered glide.
- Ground takeoff (foot-launch). v1 deploys from spread-eagle posture
  in freefall or from a high stationary platform (cliff/tower); not a
  running takeoff.
- Powered landing without parachute. No.
- Certification path. Experimental research aircraft under existing
  skydiving regs.

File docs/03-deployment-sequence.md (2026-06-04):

# 03 — Deployment Sequence

**Status:** First-cut closed. The state machine, sensed handshakes, and abort
paths are specified and a runnable simulator validates them
(`analysis/deployment/state_machine.py`). The companion **symmetry budget
fails** the BRIEF 10 ms 3-σ gate with the locked architecture — see
`docs/02b-symmetry.md` (or section "Symmetry budget closure" below) for the
architecture revisions that close it. Resolution is required before any
flight-relevant test article is built.

This document defines the safety case the program is built around. Every
transition gate, every abort path, every sensor channel listed below has
implications downstream: spar-lock sensors get specified in `cad/jettison/`,
the alpha limiter inherits the FCS-fault path, and the ground deployment rig
exists to characterize every contributor in the timing budget.

## State machine

```
                        +──── pilot_arm ────────────────────►
                        │                                     │
       ┌────────────┐   │   ┌────────────┐                   │
       │   INIT     ├───┘   │   ARMED    │   accel < 0.3 g, 200 ms dwell
       └────────────┘       └─────┬──────┘
                                  │
                                  ▼
                            ┌──────────┐
                            │ FREEFALL │   body_rates < 0.5 rad/s, 1 s dwell
                            └─────┬────┘
                                  ▼
                            ┌────────────┐
                            │ STABILIZE  │ ──── (issue drogue extract cmd)
                            └─────┬──────┘
                                  ▼
                       ┌───────────────────────┐
                       │  DROGUE_INFLATING     │
                       └─────┬─────────────────┘
                load ≥ 50 %  │   load fail / timeout 4 s
                airspeed < 32│   ──────► JETTISON + RESERVE
                m/s          ▼
                      ┌────────────────┐
                      │ DROGUE_STABLE  │ ──── (issue wing deploy cmd)
                      └──────┬─────────┘
                             ▼
                     ┌────────────────────┐
                     │   WING_DEPLOY      │
                     └──────┬─────────────┘
       all 6 spar-lock OK   │   any-lock-fail / Δt > 10 ms 3-σ / timeout 0.5 s
       Δt_LR ≤ 10 ms        │   ──────► JETTISON + RESERVE
                             ▼
                     ┌─────────────────────┐
                     │ WING_TRIM_ACQUIRE   │
                     └──────┬──────────────┘
            FCS healthy +   │
            airspeed window ▼
                     ┌─────────┐
                     │  GLIDE  │   ← steady state
                     └─────────┘
```

**Parallel abort monitors** active from ARMED onward override every state and
go directly to `JETTISON_RESERVE`:

- `pilot_abort` (manual handle pull, two-action requirement to prevent inadvertent fire)
- `aad_fire AND altitude < 200 m AGL` (AAD-triggered, FCS-bypassed)
- `fcs_fault` (irrecoverable; if airworthy, `MECHANICAL_REVERSION` instead of jettison)

## Phase budgets (nominal)

From the simulator's nominal scenario (`make_nominal_scenario`):

| Phase | Entry trigger | Duration (s) | Exit gate |
|---|---|---|---|
| ARMED → FREEFALL | exit detected | 0.2 (dwell) | accel < 0.3 g, 200 ms dwell |
| FREEFALL → STABILIZE | rates settled | 1.0 (dwell) | rate_mag < 0.5 rad/s, 1 s dwell |
| STABILIZE → DROGUE_INFLATING | drogue extract cmd | < 5 ms | command issued |
| DROGUE_INFLATING → DROGUE_STABLE | drogue load + airspeed | ~2.6 (typical) | load ≥ 50 % AND V < 32 m/s |
| DROGUE_STABLE → WING_DEPLOY | wing deploy cmd | < 5 ms | command issued |
| WING_DEPLOY → WING_TRIM_ACQUIRE | spar locks + symmetry | ~0.45 | all 6 locks AND Δt ≤ 10 ms |
| WING_TRIM_ACQUIRE → GLIDE | trim captured | ~0.005 | FCS healthy, airspeed window |
| Total exit-to-glide | | **~5 s** | |

## Sensor channels and gates

Every gate is multi-channel; single-sensor failures must not cause unsafe
progression.

| Sensor | Used for gate(s) | Redundancy |
|---|---|---|
| IMU (3-axis accel + gyro) | ARMED→FREEFALL, FREEFALL→STABILIZE, abort | Triplex IMUs (Pixhawk + redundant FCS + standalone aux) |
| Pitot-static | DROGUE_INFLATING→STABLE airspeed gate, trim capture | Dual pitot booms; if both lost, GNSS-derived ground speed as degraded fallback |
| Drogue load cell | DROGUE_INFLATING→STABLE | Dual-bridge cell on bridle; cross-check vs accel signature |
| Spar-lock microswitches (6) | WING_DEPLOY → WING_TRIM_ACQUIRE | One per stage per side (3 stages × 2 sides); dual contacts on each |
| Skin tension load cells (4) | (advisory only — not a gate) | 2 per side at chord stations |
| AAD signal | global abort | independent of FCS power and bus |
| Pilot manual abort | global abort | mechanical handle + two electrical switches |
| FCS health monitor | global abort, mechanical reversion | both FCS units cross-check |

**Critical:** the WING_DEPLOY→WING_TRIM_ACQUIRE gate has two parts:
1. *all 6 spar-lock sensors confirm full extension*
2. *time delta between left-side fully-locked and right-side fully-locked is
   ≤ 10 ms (the BRIEF symmetry gate)*

The second part requires high-resolution timestamping of the lock events.
Lock-sensor channels need ≤ 1 ms latency from physical close to FCS read,
which drives both sensor selection (no software-debounced microswitches with
> 1 ms timer) and bus design (interrupt-driven GPIO, not polled).

## Abort paths

| Trigger | Time-to-decision | Action |
|---|---|---|
| Drogue load < 50 % at 4 s after extract | 4 s timeout | Bypass drogue, command immediate jettison if airworthy; pilot reserve otherwise |
| Spar-lock sensor mismatch (any side incomplete) at 0.5 s after deploy cmd | 0.5 s | Jettison + reserve |
| Asymmetric deploy: Δt_LR > 10 ms when both sides complete | < 1 ms after second side locks | Jettison + reserve |
| Pilot manual abort | continuous, < 50 ms | Jettison + reserve |
| AAD altitude trigger | continuous, < 100 ms | Jettison (FCS-bypassed) + reserve |
| FCS irrecoverable fault during deploy | continuous | Jettison + reserve |
| FCS irrecoverable fault during glide | continuous | Mechanical reversion to direct cable (preferred); jettison if airworthy revision lost |

The asymmetric-deploy detector is the dominant case per BRIEF. Detection is
in two channels:
- per-side completion timestamps (the ≤ 10 ms gate)
- attitude / roll-rate divergence outside the ARMED window

When **either** triggers, jettison fires.

## Phase C: bistable rib unroll (deployment physics)

The wing's chordwise section is set by **9 ribs per side**, and these are *not*
rigid struts that swing out — they are **bistable rolled-composite tape-springs**
(thin-ply high-strain carbon, ACS3/CTM-class lenticular section). Each rib is
stowed as a flat **coil at the leading-edge spar hub** and self-deploys by
releasing the elastic strain energy locked in the coiled shell, snapping onto
the airfoil and self-latching open. This is the mechanism the 3D model animates
(`sim/build.py: Mesh.rib_unroll`, a real coil→airfoil geometry, not a thickness
fake) and that the reduced-order model `analysis/deployment/rib_deploy_rom.py`
simulates.

**Why the ribs roll but the spars don't.** A reeled thin-shell boom delivers
bending stiffness *EI* ≈ 10²–10³ N·m². The wing **spar** must carry the ~1.5 kN·m
root moment at 3 g, which needs *EI* ≈ 3.4×10⁴ N·m² — two orders of magnitude
more — and a wall thick enough to do that cannot coil without exceeding the
shell's failure strain (ε = t/2R). So the **primary spars stay rigid** (67 mm
CFRP, telescoping booms; see `docs/02`) and the rollable/bistable mechanism is
used where the loads are low enough for it to work — the **ribs**.

**ROM results** (`rib_deploy_rom.py`, Seffen–Pellegrino constant propagation
moment + bistable double-well + damped hub):

| Quantity | Value | Note |
|---|---|---|
| Shell wall t | 0.14 mm | thin-ply HSC carbon |
| Coil radius | 11 mm | at the spar hub |
| Coil strain ε = t/2R | 0.64 % | within ~1 % HSC allowable |
| Propagation moment M\* = (1+ν)·D·α | 2.14 mN·m | constant (steady uncoiling) |
| Driving force F = M\*/r_coil | 195 mN | constant strain-energy drive |
| **Per-rib snap time** | **≈ 0.69 s** | coil → latched airfoil |
| **Latch-contact velocity** | **1.96 m/s** | damper-regulated, soft |
| End-latch shock | 27 N | << the 195 N latched root carries |
| Passive friction hold / drive | 0.13× | **insufficient — see below** |

**Blossoming guard (a design driver).** Inter-layer friction alone holds only
0.13× the steady tip force, so a *free* friction coil would **blossom** (unwind
loosely inside the deployer instead of feeding the front under tension). That is
why the hub is a **rate-controlled spool** — a rotary viscous damper meters the
payout, which simultaneously (a) prevents blossoming and (b) bleeds the stroke
so the rib reaches its end-stop at only ~1.96 m/s (no destructive snap).
Bistable end-detents then hold both the stowed and the deployed states without
a restraint band. The 9 ribs/side fire on a **root→tip stagger** so the unfurl
front sweeps outboard across Phase C — the schedule the animation renders.

This per-rib snap dispersion is the `Tape-spring snap dispersion (9 ribs/side)`
contributor (σ = 1.2 ms) in the symmetry table below; the nominal per-rib snap
time and soft-latch velocity are now sourced from this ROM rather than assumed.

## Phase D: skin membrane form-finding (deployment → controlled surface)

The deployment doesn't just unfold the structure — it has to leave a *fair,
controllable* aerodynamic surface. The skin is a **pretensioned membrane**
stretched over the bistable ribs: the telescoping booms pull it taut spanwise
and the rib snap tensions it chordwise. The bay between two ribs then sags under
the aerodynamic pressure, and that sag is the waviness off the design airfoil.

From membrane statics (`analysis/deployment/membrane_formfinding.py`,
`δ = q·s²/(8·N)`, cross-checked by discrete relaxation), with the deployment
delivering ~2.2 kN/m of skin pretension:

| Quantity | Value |
|---|---|
| Net skin pressure (1 g / 3 g) | 158 / 475 Pa |
| Worst inter-rib sag @ 3 g | ≈ 1.9 mm |
| **Surface waviness δ/c @ 3 g** | **0.16 – 0.27 %** (inside the 0.4 % tol) |
| Skin in tension (wrinkle-free) | yes |

So the deployed wing is a **smooth controlled surface** — and a clean
trailing-edge flaperon — not a billowing ram-air canopy. The pretension is
itself a deployment requirement: the booms + rib snap must deliver it for the
surface to come out fair, which links the deployment mechanism directly to the
final aerodynamic quality. The 3D model (`sim/build.py`) renders this physical
sag (≈1.5 % of section thickness), replacing the earlier ad-hoc 14 % bulge.

## Symmetry budget closure

The Monte-Carlo error stack-up
(`analysis/deployment/symmetry_budget.py`, 50,000 trials) gives the locked
architecture's combined left-right deploy-time variance:

| Contributor | σ (ms) | 3-σ contribution to Δt (ms) |
|---|---|---|
| CO2 cartridge fill mass / temperature | 2.5 | 10.6 |
| Valve port differential | 0.8 | 3.4 |
| Manifold flow impedance match | 1.5 | 6.3 |
| Spar telescope friction (cold/wet) | 2.0 | 8.5 |
| Tape-spring snap dispersion (9 ribs/side) | 1.2 | 5.1 |
| **Combined 3-σ |Δt|** | | **16.3 ms** |

> 16.3 ms 3-σ vs the 10 ms BRIEF gate. **Fails by 6 ms.**

The CO2 cartridge variance alone (10.6 ms 3-σ) busts the gate before any
other contributor is added. Sensitivity analysis confirms it's the single
biggest knob.

### Architecture options that close the budget

| Option | Description | 3-σ |Δt| (ms) | Status |
|---|---|---|---|
| A | Shared CO2 reservoir (one bottle, one regulator, common-mode flow) | 12.9 | FAIL |
| B | Active per-side flow modulation (sense progress, modulate valve) | **8.1** | **PASS** |
| C | Mechanical-spring primary, CO2 only unlocks the latches | 10.1 | FAIL by 0.1 ms |

**Recommendation:** adopt **option B** — active per-side flow modulation
with closed-loop sensing of stage-lock progress on each side. This is a
first-order architecture change to BRIEF decision #5 ("sequenced from a
single valve to enforce sub-10ms left/right symmetry") — replace passive
sequencing with active control.

Combined options (A+B or B+C) close the budget with much more margin and are
worth comparing once bench data tightens the input distributions.

## Ground rig requirements driven by this analysis

The symmetry budget's input distributions are conservative engineering
estimates. Each one needs to be measured on the bench before treating the
final 3-σ as authoritative. The ground deployment rig
(`test/ground/spec.md`) is the instrument that does the measurement —
each contributor maps to a specific instrumented test campaign:

- **CO2 cartridge variance** ← thermal + cartridge-batch sweep, mass-flow
  metering at the manifold output.
- **Manifold balance** ← differential pressure across each side's port
  during firing, repeated.
- **Spar friction** ← stage-lock-time recordings under temperature and
  humidity conditioning, with intentional water/ice ingress.
- **Tape-spring snap dispersion** ← per-rib unfurl-time recordings via
  high-speed video frame extraction.

Once those inputs are measured, the budget closes (or doesn't). The
current 16 ms result is a *prediction* — the rig is the *measurement*.

## Open issues / verification gates

1. **Adopt option B.** Update BRIEF architecture decision #5. Active flow
   modulation requires per-side stage-lock progress sensors — already in
   the sensor list above, but their use needs to be tighter than just
   gating completion.
2. **Lock-sensor latency.** Specify ≤ 1 ms hardware response from contact
   close to FCS register; verify on bench.
3. **Asymmetric-deploy false-positive rate.** With a 10 ms gate and the
   current input distributions, the false-positive jettison rate at deploy
   is ~25 % (option B drops it to ~1 %). Unacceptable until option B is
   in place.
4. **AAD interface independence.** Wire AAD trigger directly to cutter
   firing circuit, not through FCS. Detail in `safety/failure-modes/aad-fault.md`.
5. **Pilot abort handle reachability.** Mechanical and reach geometry under
   deployed-wing pilot configuration — closes via `cad/harness/`.
6. **Mechanical reversion.** Surfaces, cable routing, transition logic in
   `docs/04-fcs-architecture.md`.

## Reproducibility

```sh
# Nominal scenario trace + state machine validation
PYTHONPATH=. .venv/bin/python -m analysis.deployment.state_machine

# Symmetry budget Monte Carlo with sensitivity sweep
PYTHONPATH=. .venv/bin/python -m analysis.deployment.symmetry_budget

# Bistable rib unroll physics (snap time, soft-latch velocity, blossoming guard)
PYTHONPATH=. .venv/bin/python analysis/deployment/rib_deploy_rom.py

# Skin membrane form-finding (deployment tensions the skin into a controlled
# surface: bay sag, waviness vs aero tolerance, wrinkle-free check)
PYTHONPATH=. .venv/bin/python analysis/deployment/membrane_formfinding.py

# Tests
PYTHONPATH=. .venv/bin/python -m pytest analysis/deployment/tests/ -v
```

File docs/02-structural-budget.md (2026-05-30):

# 02 — Structural Budget

> **⚠ Resized planform.** Authored for the 8.4 m² / 7.4 m wing; the wing is now
> **6.5 m² / 6.3 m** (BRIEF findings #5/#6). `analysis/struct/out/` data + plots
> are regenerated — re-run `make struct`. Headline deltas: bending-sized front
> spar root **67 mm** OD (was 73) — shorter span → less root moment; wing-system
> mass **~16.3 kg**; telescoping boom 2.9 → **2.4 m/side**.

**Status:** First-cut closed. The analysis has surfaced two binding tensions
with `BRIEF.md` that need a decision before structural design proceeds:

1. **The locked spar dimensions (front 40 mm OD / 2 mm wall) fail the bending
   case at 3 g limit by a factor of ~3 in stress.** Recommended sizing: 67 mm
   OD root / 2.5 mm wall. (Section "Spar bending" below.)
2. **The 15.5 kg wing-system mass target cannot be met** with the
   bending-correct spar. Recommended budget: **~16.6 kg** with a properly
   sized front spar, or a different load-case decision. (Section "Mass
   budget".)

Both are evidence-driven flags per the BRIEF rule "Architecture decisions
locked unless evidence forces a change." Resolution paths are in the
recommendations at the end.

## Methodology

- Span loading from the Weissinger lifting-line solver at design CL = 0.5
  (`analysis/aero/weissinger/`). This captures the actual sweep-and-taper
  loading shape rather than approximating with elliptical.
- Cantilever bending-moment integration along each half-wing, validated
  against analytical cases (uniform line load and elliptical loading) in
  `analysis/struct/tests/test_struct.py` to <1 %.
- Section properties from a parametric telescoping-spar model
  (`analysis/struct/spar_model.py`).
- Material allowables from `analysis/struct/materials.py` (T800/epoxy UD
  CFRP tube, knockdown 0.55, FAR 1.5× ultimate-over-limit factor).
- Brazier critical-moment check for thin-walled CFRP tubes under bending.

## Materials

| Property | Value | Source |
|---|---|---|
| ρ (CFRP UD tube) | 1580 kg/m³ | Toray T800S/3900-2 datasheet, 2024-09 |
| σ_ult tension | 1900 MPa | T800 layup ~85 % axial UD |
| σ_ult compression | 1100 MPa | fiber-kinking limit |
| knockdown (env × fatigue × notch) | 0.55 | DOT/FAA composite handbook + Niu Ch. 5 |
| safety factor (limit→ult) | 1.5 | FAR Part 23 / EASA convention |
| **σ_design_compression_limit** | **403 MPa** | knockdown × ult / SF |

DCF skin areal density: 50 g/m² (mid-weight CT3K series).

## Span loading at design CL

The Weissinger solver gives the normalized span loading shape at α = 7.66°,
CL = 0.5. Total wing lift at n_load · m_total · g is distributed across
the span proportional to `cl(y)·c(y)`, then integrated as a cantilever
moment about each spanwise station.

For sizing, the **upper-end pilot mass** in the BRIEF envelope is used:

| Quantity | Value |
|---|---|
| Pilot mass (sizing) | 95.0 kg |
| Wing + rig mass | 23.5 kg |
| Total mass for sizing | 118.5 kg |
| Lift at 1 g | 1162 N |
| Lift at 3 g | 3487 N |
| Lift at 4.5 g | 5230 N |

## Spar bending — `analysis/struct/spar_bending.py`

### Chordwise load split

The two-spar layout splits the wing's lift between front and rear spars
based on the chordwise position of each spar relative to the lift action
line (the AC at ~0.25·c).

With the BRIEF nominal spar positions (front at 0.20·c, rear at 0.65·c):

> f_front = (x_rear − x_AC) / (x_rear − x_front) = (0.65 − 0.25) / (0.65 − 0.20) = **0.889**

So the front spar carries ~89 % of the wing bending load. Moving the front
spar to 0.10·c would drop this to 0.73, but at the cost of LE structural
real estate (interferes with stowed-state packaging and tape-spring rib
coil routing).

### Stress at the root — BRIEF dimensions

With BRIEF spar dimensions (front 40 mm OD / 32 mm mid / 25 mm tip / 2 mm
wall; rear 30 mm / 24 mm / 18 mm / 2 mm wall):

| Load case | Spar | M_root (N·m) | σ_root (MPa) | SF_strength | SF_buckling (Brazier) |
|---|---|---|---|---|---|
| 1 g cruise | front | 830 | **384** | **1.05** | 110 |
| 3 g limit | front | 2491 | **1153** | **0.35** | 37 |
| 4.5 g ult. | front | 3737 | **1729** | **0.23** | 24 |
| 1 g cruise | rear | 104 | 90 | 4.49 | 494 |
| 3 g limit | rear | 311 | 270 | 1.50 | 165 |
| 4.5 g ult. | rear | 467 | 404 | 1.00 | 110 |

**The front spar fails:** SF_strength = 0.35 at 3 g limit means the spar
is undersized by a factor of ~3 in stress capacity. At 1 g cruise it's
right at the design-limit margin (SF = 1.05) — no growth room and no
gust-load tolerance.

The rear spar passes (SF = 1.00 at 4.5 g ultimate, exactly the FAR
threshold). It does not need re-sizing. **Buckling (Brazier) is not the
binding constraint** — buckling SF is two orders of magnitude above the
strength SF for both spars.

### Wall-thickness sensitivity (BRIEF OD progression)

Holding the BRIEF OD progression and varying wall:

| Wall (mm) | Front mass (kg/side) | σ_root @ 3 g (MPa) | SF_strength |
|---|---|---|---|
| 1.5 | 0.96 | 1480 | 0.27 |
| 2.0 | 1.24 | 1153 | 0.35 |
| 2.5 | 1.51 | 958 | 0.42 |
| 3.0 | 1.76 | 830 | 0.49 |

Doubling the wall (to 4 mm) would still leave SF < 0.7. Wall thickness
alone cannot save the BRIEF dimensions.

### OD sensitivity at 2.5 mm wall

The binding parameter is OD (because I scales with D³ for thin walls).
At 2.5 mm wall, with stage progression OD_root / 0.7·OD_root / 25 mm:

| OD_root (mm) | Front mass (kg/side) | σ_root @ 3 g (MPa) | SF_strength |
|---|---|---|---|
| 40 | 1.44 | 958 | 0.42 |
| 50 | 1.71 | 590 | 0.68 |
| 60 | 1.98 | 400 | 1.01 |
| 65 | 2.12 | 337 | 1.20 |
| 70 | 2.25 | 288 | 1.40 |
| 80 | 2.52 | 218 | 1.85 |

### Recommended front spar

- **OD_root = 67 mm**, OD_mid = 51 mm, OD_tip = 25 mm
- **Wall = 2.5 mm**
- 3-stage telescoping, stage length 1.283 m each (joint overlap 50 mm)
- Per-side mass: **2.34 kg** (vs. BRIEF default 1.24 kg → **+1.10 kg/side**)

Result: σ_root = 264 MPa at 3 g limit, SF_strength = 1.53. Comfortable
margin against the 403 MPa allowable.

## Mass budget — `analysis/struct/mass_budget.py`

### Component roll-up — BRIEF spar dimensions (NB: spar fails bending)

| Component | Mass (kg) | % of 15.5 target |
|---|---|---|
| Spars (4 spars, both sides) | 4.32 | 27.9 % |
| Ribs (9 per side, 18 total, tape-spring) | 1.14 | 7.3 % |
| Skin (DCF + bond overhead) | 0.95 | 6.1 % |
| Root fittings + cutters | 1.60 | 10.3 % |
| Pneumatic deployment | 0.73 | 4.7 % |
| Flight control system | 0.86 | 5.5 % |
| Actuators + reversion | 0.97 | 6.3 % |
| Drogue + bridle | 0.35 | 2.3 % |
| Harness shell + interface | 2.00 | 12.9 % |
| Margin (10 % of allocated) | 1.29 | 8.3 % |
| **Total** | **14.21** | **91.7 %** |

`14.21 kg < 15.5 kg target — but the spar in this configuration fails
bending. Not a usable design.`

### Component roll-up — bending-sized front spar (67 mm/2.5 mm)

| Component | Mass (kg) | % of 15.5 target |
|---|---|---|
| Spars (4 spars, both sides) | **6.51** | **42.0 %** |
| Ribs | 1.14 | 7.3 % |
| Skin | 0.95 | 6.1 % |
| Root fittings + cutters | 1.60 | 10.3 % |
| Pneumatic deployment | 0.73 | 4.7 % |
| FCS | 0.86 | 5.5 % |
| Actuators + reversion | 0.97 | 6.3 % |
| Drogue | 0.35 | 2.3 % |
| Harness | 2.00 | 12.9 % |
| Margin (10 %) | 1.51 | 9.7 % |
| **Total** | **16.62** | **107.2 %** |

**+1.12 kg over the 15.5 kg BRIEF target.**

### Sensitivity sweep

The wing system's mass is most sensitive to spar sizing. Skin areal
density and rib count are second-order:

| Front spar | Ribs/side | Skin g/m² | Total (kg) | Δ vs target |
|---|---|---|---|---|
| BRIEF | 7 | 40 | 13.72 | −1.78 |
| BRIEF | 9 | 50 | 14.21 | −1.29 |
| BRIEF | 11 | 60 | 14.70 | −0.81 |
| **SIZED** | 7 | 40 | 16.13 | **+0.63** |
| **SIZED** | 9 | 50 | 16.62 | **+1.12** |
| **SIZED** | 11 | 60 | 17.11 | **+1.61** |

Even the leanest sized configuration (7 ribs, 40 g/m² skin) is +0.63 kg
over budget. Reducing ribs below 7 risks skin sag between ribs and tip
flutter; reducing skin below 40 g/m² loses tear resistance.

## Recommendations

### 1. Adopt the bending-sized front spar.

OD_root 67 mm, OD_mid 51 mm, OD_tip 25 mm, wall 2.5 mm. This is the
smallest spar that closes the bending case at 3 g limit / 4.5 g ultimate
with a 1.5× margin on the design-limit stress. **Update BRIEF
architecture decision #1 to reflect this.**

### 2. Update wing-system mass budget to ~16.6 kg.

That's the lowest credible budget given a structurally adequate spar
and the rest of the systems sized as in the build-up. Wing loading
becomes ~12.9 kg/m² (vs. BRIEF nominal 10.5 kg/m²). The aero pipeline's
stall-speed and best-glide numbers would shift slightly — re-run
`make aero` after the change.

### 3. Alternatively, reduce the design n_load.

A non-aerobatic glider with mandatory alpha-limiter envelope protection
could justify a 2.5 g limit (3.75 g ultimate) instead of 3 g/4.5 g. At
2.5 g limit the front spar requirement drops to ~62 mm OD / 2.5 mm wall
and the total budget closes at ~15.7 kg — within ~0.2 kg of the BRIEF
target.

This requires a separate gust-load analysis to defend (a 7.5 m/s gust at
V = 25 m/s gives Δn ≈ 2 g for this wing loading and CL_α — so 2.5 g
limit leaves only 0.5 g margin against a moderate gust, which is
borderline). Not recommended without a serviceable alpha-limiter prototype
first.

### 4. Don't attempt to save mass by reducing knockdowns.

The 0.55 knockdown is conservative but defensible. Reducing it requires
coupon test data the program doesn't yet have — no shortcut here.

## Sized-spar 3D model

`cad/spars/build.py` exports both BRIEF and sized configurations:

- `cad/spars/out/spars_brief.step`  (40/32/25 mm, fails bending)
- `cad/spars/out/spars_sized.step`  (67/47/25 mm, recommended)

Same for `.stl`. The sized spar visibly larger at the root — it's a
significant change to the wing's stowed-package thickness budget too,
since the stowed (telescoped) bundle is now 67 mm in the front-spar
diameter (vs. 40 mm BRIEF) plus the rear spar plus the tape-spring
ribs and skin folded around them. The BRIEF "stowed package thickness
< 15 cm off body profile" constraint may also need re-examination.

## Drogue snatch — harness-mount load case

The drogue dynamics analysis ([`analysis/deployment/drogue_dynamics.py`](../analysis/deployment/drogue_dynamics.py))
sizes the drogue at 1.84 m diameter (CdA = 1.47 m²) and predicts a
**peak bridle tension of 3.94 kN at t = 0.45 s** post drogue-extract
command. This corresponds to a 3.83 g equivalent vehicle decel —
between 3 g flight limit and 4.5 g ultimate.

The bridle attaches to the **harness**, not the spar roots. The spar
bending analysis above does NOT see this load in the nominal sequence.
But the harness mount (and the bridge that carries the wing-mount
sub-frame) must be sized to the drogue case rather than to the 3 g
flight load — the drogue snatch is the binding harness-mount case.

Cross-coupling exception: an asymmetric-deploy event with the drogue
still attached can transmit drogue tension into the spar roots via
the wing-harness interface for ~75 ms before jettison fires. This is
not yet sized; current `analysis/struct/spar_bending.py` treats only
the symmetric flight load. A coupled-asymmetric-deploy load case is
in the open-issues list below.

## Open verification gates

1. **FEA validation of the root joint** under combined bending + cutter
   interface load — the analytical hand-calc here treats the root as a
   simple cantilever with no joint compliance. The pyrotechnic-cutter
   joint is a stress concentrator and a discontinuity; FEA needed.
2. **CFRP coupon tests** to defend knockdown 0.55 for the actual layup
   chosen. Vendor B-basis from a qualified prepreg + qualified shop
   could reduce the knockdown and unlock mass savings.
3. **Gust-load analysis** to defend the 3 g (or proposed 2.5 g) limit.
4. **Tape-spring rib actual mass** — the 50 g/rib estimate here is a
   first-cut; lab-measured prototypes will tighten this.
5. **Stowed-package thickness budget** with the sized spar in the
   stowed configuration. The BRIEF < 15 cm constraint may bind.
6. **Asymmetric-deployment transient load** — at the moment we have not
   sized for the bending+torsion case during a partial-deploy event.
   That goes into `analysis/deployment/` and a follow-up update of
   this document.

## Reproducibility

```sh
make struct      # full pipeline: bending + budget
PYTHONPATH=. .venv/bin/python -m pytest analysis/struct/tests/ -v
PYTHONPATH=. .venv/bin/python cad/spars/build.py
```

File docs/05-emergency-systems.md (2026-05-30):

# 05 — Emergency Systems

**Status:** First-cut closed. Pulls together jettison logic, AAD
integration, reserve compatibility, asymmetric-deployment detection.
References the per-failure-mode write-ups for the binding analysis.

## Locked from BRIEF

- Four pyrotechnic cutters at the spar roots fully jettison the wing
  assembly.
- Triggers: pilot manual command, AAD activation, FCS detection of
  asymmetric deployment.
- After jettison, the underlying piggyback skydiving rig functions
  normally for canopy flight and landing.
- Reserve canopy must deploy clean over the head with no wing-structure
  occlusion.

## Cutter system

Four pyrotechnic spar-root cutters, one per spar root (front-left,
front-right, rear-left, rear-right).

| Property | Spec |
|---|---|
| Cutter type | Linear shaped charge (LSC), aluminum housing wrapping the spar root just outboard of the bonded fitting |
| Cut diameter | Front: 67 mm sized spar OD + 5 mm wall ferrule clearance; rear: 30 mm |
| Initiator | NASA-style standard initiator (NSI) or equivalent, dual per cutter (independent pyrotechnic + electrical paths) |
| Cut time | < 5 ms after fire signal received (LSC propagation) |
| No-fire margin | 1 W / 1 A for 5 minutes (B-basis, 95/95 confidence — defended by vendor coupon tests) |
| All-fire margin | 3.5 A for 50 ms |
| Operating environment | −20 °C to +50 °C, 95 % RH, sealed against rain/spray |
| Lockout | Mechanical pin (manual remove pre-flight) + electrical arm enabled by FCS state machine |

Per-cutter sourced from a qualified aerospace pyrotechnic vendor (e.g.
PacSci, Special Devices, or Ensign-Bickford). Selection criteria
documented in `cad/jettison/` after vendor consultation.

## Trigger sources

```
                       ┌── pilot manual abort handle ──┐
                       │                                │
                       ├── deployment SM                │
                       │     • asymmetric Δt > 10 ms    │
                       │     • spar-lock fail timeout   ├──► cutter
                       │     • drogue mal timeout       │      firing
                       │     • combined-mode aborts     │      circuit
                       │                                │
                       ├── FCS-bypass: AAD trigger      │
                       │     (independent power rail)   │
                       │                                │
                       └── ground-test override         ┘
                            (lockout disable cmd, ground only)
```

### Pilot manual abort

Mechanical handle on the harness, reachable in the deployed-wing
configuration. **Two-action requirement** to prevent inadvertent fire:
either two simultaneous switches (one mechanical, one electrical) or a
guarded handle requiring a deliberate two-handed pull. Reach geometry
verified in [`cad/harness/`](../cad/harness/) once the harness CAD is
built.

### FCS-detected aborts

Per [`docs/03-deployment-sequence.md`](03-deployment-sequence.md):

| Trigger | When |
|---|---|
| Asymmetric deploy: Δt_LR > 10 ms once both sides locked | < 1 ms after second-side lock |
| Spar-lock fail: any-channel-incomplete by 0.5 s after deploy cmd | 500 ms timeout |
| Drogue mal: load < 50 % at 4 s after extract | 4 s timeout |
| Roll-rate divergence: > 1.5 rad/s during deploy window | continuous monitor, 200 ms window |
| FCS irrecoverable fault during deploy | continuous |

### AAD trigger (FCS-bypassed)

The AAD has TWO outputs:
1. **Standard skydiving function** — fires the reserve container's
   built-in cutter (severs the closing loop). This works whether or not
   the wing is attached.
2. **MANTA-specific output** — a GPIO that drives the wing-cutter firing
   circuit DIRECTLY, bypassing the FCS. Independent power rail (the
   AAD's own battery), independent wiring, independent timing.

Sequence on AAD trigger:
- t=0: AAD detects altitude < threshold AND descent rate > threshold
- t=0: AAD GPIO fires → wing cutters fire
- t=+5 ms: cutters complete cut
- t=+30 ms: wing assembly mechanically separates
- t=+100 ms (programmed delay in AAD): standard reserve cutter fires
- t=+200 ms: reserve canopy bag launches

The 100 ms delay between wing-cutter fire and reserve-cutter fire is
the critical interlock — the wing must be CLEAR before the reserve
launches.

## Detected asymmetric-deployment response

This is the dominant case (per `safety/failure-modes/asymmetric-
deployment.md`). The full response is:

1. State machine detects Δt_LR > 10 ms or roll-rate > 1.5 rad/s.
2. Cutter firing circuit fires all 4 cutters simultaneously (≤ 5 ms after detection).
3. Wing assembly separates from the harness within 30 ms of cut.
4. State machine commands reserve deployment (or pilot does manually if
   FCS unable).
5. Reserve canopy inflates over the next 1.5–3 s.

Time from detection to fully-inflated reserve: < 4 s. Altitude loss in
that window at 30 m/s descent rate: ~120 m. Combined with the AAD
threshold of 200 m AGL, this leaves no margin for AAD-initiated abort
below ~320 m AGL — practically, the operational deployment altitude
floor is **~600 m AGL** to give margin to the AAD case if the BRIEF
asymmetric-detect path fails.

## Reserve compatibility

Detailed in [`safety/reserve-compat.md`](../safety/reserve-compat.md).
Summary of geometric constraints:

- Pre-jettison: harness does not interfere with reserve container,
  ripcord, RSL, or AAD function.
- Post-jettison: stubs at the four root fittings are < 80 mm long, in
  the chord plane only (no vertical projection into the reserve
  deployment cone), with rounded ferrule ends to prevent line snags.
- Reserve canopy launches in the +z hemisphere; clear of any
  post-jettison structure.
- Standard skydiving rig main canopy is unobstructed.
- Pilot can fly canopy and land normally with the harness mount in
  place (the bolted-down sub-frame stays with the rig; the wing
  assembly leaves on jettison).

## Verification gates

| Gate | Status | Where verified |
|---|---|---|
| Cutter no-fire / all-fire margins (per cutter) | Open | Vendor coupon tests + acceptance test per shipset |
| Cutter EMI immunity (HIRF / lightning per RTCA DO-160 G H) | Open | Bench EMI test |
| Lockout cycle test (mechanical + electrical) | Open | Bench |
| First firing on a complete wing assembly | Open | Ground rig (`test/ground/`) — the FIRST live cutter event in the program |
| Asymmetric-deploy firing on instrumented drop article | Open | Drop article (`test/drop/`) |
| Reserve clearance: symmetric + asymmetric jettison | Open | Drop article + bench mock-up |
| AAD interface integration | Open | Bench integration with selected AAD vendor |
| Pilot-handle reachability in deployed-wing configuration | Open | `cad/harness/` + bench mock-up |
| 200-cycle ground-rig gate (no lockout failures, no inadvertent fire) | Open | `test/ground/spec.md` |

Until all gates close, manned-deployment flight is not authorized. The
no-fire / all-fire and the lockout-cycle gates close BEFORE the first
ground-rig firing.

## What is *not* an emergency-system feature

By design:

- **No active stabilization during reserve descent.** Once the wing is
  jettisoned, the FCS is not in the loop — it's a normal skydiving
  reserve event.
- **No re-deployment of the wing in flight.** A jettison is one-way.
  No procedure for re-stowing in flight; the next deployment is on a
  re-packed assembly on the ground.
- **No partial jettison.** All four cutters fire together. A single-side
  jettison would leave a flapping half-wing and is not a valid mode.

## Open issues

1. **AAD vendor integration sign-off.** Need to confirm that the chosen
   AAD's GPIO supports the timing and electrical isolation MANTA
   requires.
2. **Cutter vendor selection.** Down-select from PacSci / SDI /
   Ensign-Bickford based on cost, lead time, NSI availability, and
   ability to deliver ≤ 5 ms cut on the 67 mm front-spar size.
3. **Stub geometry confirmation.** Once `cad/harness/` is built,
   confirm the stub-vs-reserve-cone clearance with a real harness
   placement, not the placeholder used here.
4. **Re-pack procedure documentation.** Once the cutters are integrated,
   write a rigger SOP for re-arming the cutters after a jettison event
   (post-incident).

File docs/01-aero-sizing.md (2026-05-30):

# 01 — Aero Sizing

> **⚠ Resized planform.** This write-up was authored for the original
> 8.4 m² / 7.4 m wing. The wing was downsized to **6.5 m² / 6.3 m, AR 6.1, 7°
> washout** (BRIEF findings #5/#6). The scripts + `analysis/aero/*/out/` data +
> plots are regenerated for the current planform — re-run `make aero` for live
> numbers. Headline deltas: CL_α 4.24 → **4.17 /rad**; V_bg ~16 → **18.3 m/s**;
> (L/D)ₘₐₓ 12.0 → **11.6**; root chord 1.62 → **1.47 m**; trim SM at 7° washout
> **5.6 %** (binding CG-based margin ~2.7 %).

**Status:** First-cut closed. AVL and XFOIL verification pending; trim
parameters and architecture decisions flagged for review where the analysis
surfaces tension with `BRIEF.md`.

This document summarizes deliverable #1: planform sizing, airfoil selection,
trim, stability, and L/D verification. The supporting analysis lives in
`analysis/aero/`. Numbers in this doc are reproducible from
`make aero` (and the AVL/XFOIL targets when those tools are installed).

## Planform — locked from BRIEF, derived in `analysis/aero/planform/geometry.py`

| Quantity | Value |
|---|---|
| Wing area  S | 8.400 m² |
| Span b | 7.400 m |
| Aspect ratio | 6.519 |
| Taper λ | 0.400 |
| Root chord | 1.6216 m |
| Tip chord | 0.6486 m |
| MAC | 1.2046 m |
| y_MAC | 1.5857 m |
| Sweep LE / c/4 / TE | 25.00° / 21.83° / 11.49° |
| Wetted area S_wet | 17.30 m² |
| Geometric twist (current default) | 5° washout |

Top-view planform: `cad/wing/out/planform_top.png`.

## Airfoil — `analysis/aero/airfoil/`

**Primary candidate: MH 78** (Hepperle), 10 % t/c, mildly positive Cm0,
appropriate stall character for a tailless wing. **Alternate: MH 60.**
Selection criteria, hard-rejection thresholds, and the operational
Reynolds range (5×10⁵ at the tip near stall through 2×10⁶ at the root at
best-glide) are documented in `analysis/aero/airfoil/README.md`.

A first-cut analytic polar
(`analysis/aero/airfoil/polar_analytic.py`) stands in for the airfoil
section everywhere downstream. Uncertainty bracket on each parameter is
explicit in the file. **Replace with XFOIL data** by:

1. Drop `MH78.dat` into `analysis/aero/airfoil/airfoils/`.
2. `make xfoil` — runs polars at Re ∈ {5×10⁵, 7×10⁵, 1×10⁶, 1.5×10⁶, 2×10⁶}.

Working polar at design CL (cruise):

| α (°) | Cl | Cd | Cm₀.₂₅ | L/D₂D |
|---|---|---|---|---|
| 4 | 0.50 | 0.0086 | +0.003 | 58 |

Cm0 ≈ +0.005 (slightly positive, helping tailless trim).

## Lifting-line — `analysis/aero/weissinger/`

Method: Prandtl-style lifting line with bound vortex along the panel c/4
sweep line and section a₀ coupling. Validated against:

- Helmbold AR-correction formula (rectangular AR = 8: 4.86 /rad solver vs
  5.03 /rad analytic, **−3.4 %** — single-row chord paneling underestimates
  by a few %, AVL is the higher-fidelity follow-up).
- 2D limit (AR = 100 → 6.09 /rad vs 2π = 6.28 /rad, **−3.1 %**).
- Unswept-rectangle NP at MAC c/4.

Results for the locked MANTA planform with 5° washout, MH-78-class section:

| Quantity | Value |
|---|---|
| CL_α | **4.24 /rad** (0.0740 /deg) |
| α at design CL = 0.5 | **7.66°** |
| 3D zero-lift α | +0.90° (washout pulls it positive) |
| Neutral point (aft of root LE) | **1.118 m**  =  0.928 · MAC |
| Geometric MAC c/4 | 1.041 m  =  0.864 · MAC  (NP is 6.5 % MAC aft of geom c/4) |

Span loading is in `analysis/aero/weissinger/out/span_loading.png` — peak
section Cl is mid-outboard (y ≈ ±2 m), root cl is depressed by the swept
trailing wake's downwash, tip cl is depressed by washout.

## CD0 build-up — `analysis/aero/lift_drag/cd0.py`

Component build-up referenced to S = 8.4 m². Wing profile drag is small;
the body fairing dominates and is the first-cut unknown.

| Bracket | Body CdA | CD0_wing | CD0_body | CD0_misc | **CD0** |
|---|---|---|---|---|---|
| optimistic | 0.15 m² | 0.0076 | 0.0179 | 0.0019 | **0.0273** |
| nominal | 0.20 m² | 0.0076 | 0.0238 | 0.0022 | **0.0336** |
| pessimistic | 0.30 m² | 0.0076 | 0.0357 | 0.0029 | **0.0464** |

References: Raymer Ch. 12 friction + form factor; Hoerner §13 streamlined
bodies; CdA bracket sourced from prone-pilot freefall (~0.4–0.5 m²
unfaired) and small ultralight prone-pilot fairings (~0.10–0.18 m² when
done well).

## Glide polar — `analysis/aero/lift_drag/glide_polar.py`

CD = CD0 + CL² / (π·AR·e), with e = 0.95.

**Best-glide condition** (CDi = CD0):

| Pilot | Bracket | V_bg | CL_bg | (L/D)_max | Sink |
|---|---|---|---|---|---|
| 82.5 kg | optimistic | 16.7 m/s | 0.73 | **13.4** | 1.25 m/s |
| 82.5 kg | nominal | 15.8 m/s | 0.81 | **12.0** | 1.31 m/s |
| 82.5 kg | pessimistic | 14.6 m/s | 0.95 | **10.2** | 1.42 m/s |

**L/D at the BRIEF target V = 25 m/s** (pilot 82.5 kg):

| Bracket | CL | CD | L/D |
|---|---|---|---|
| optimistic | 0.32 | 0.0326 | **9.91** |
| nominal | 0.32 | 0.0390 | **8.29** |
| pessimistic | 0.32 | 0.0517 | **6.25** |

### Tension with BRIEF performance targets

The locked planform's natural best-glide airspeed is **~16 m/s**, not the
**25 m/s** stated in BRIEF. Hitting 25 m/s as a *cruise* speed produces
L/D ≈ 8 (nominal CD0) — below the 10:1 design target, well short of the
13:1 stretch.

There are three resolution paths; one needs to be selected before the
mass/structural budget is sized:

1. **Restate V_bg as ~16 m/s.** Carries best L/D and lowest sink rate.
   Reduces ground-cover speed; gust penetration becomes worse.
2. **Hold V = 25 m/s as a cruise speed**, accept ~8:1 L/D, and revise
   `BRIEF.md` glide-ratio targets. Best for tactical mission profiles
   that need ground speed; bad for distance.
3. **Reopen the planform.** Higher wing loading (smaller S, or more
   weight on a smaller wing) lifts V_bg. Architecture decision #4
   (BRIEF) would have to change. Not recommended without other forcing
   pressure.

**My recommendation:** Path 1. The 10:1 target is closely met at the
natural V_bg with a defensible body-fairing CdA budget; the BRIEF V_bg
appears to have been set without solving for it.

## Trim + washout iteration — `analysis/aero/trim/`

For a tailless wing, longitudinal trim closes via CG placement:

> Cm_cg(α_trim, CL_design) = Cm_apex(α_trim) + (x_cg / MAC) · CL = 0

Sweeping washout in {3°, 4°, 5°, 6°, 7°} at the BRIEF design CL = 0.5:

| Washout | α_trim | x_CG_trim | x_CG / MAC | SM | α_tip_eff | tip stall margin |
|---|---|---|---|---|---|---|
| 3° | 6.90° | 1.086 m | 0.901 | **2.71 %** | +1.88° | 9.69° |
| 4° | 7.28° | 1.075 m | 0.892 | 3.61 % | +1.75° | 9.81° |
| 5° | 7.66° | 1.064 m | 0.883 | 4.51 % | +1.63° | 9.93° |
| **6°** | **8.04°** | **1.053 m** | **0.874** | **5.42 %** | **+1.51°** | **10.05°** |
| 7° | 8.42° | 1.042 m | 0.865 | 6.32 % | +1.39° | 10.18° |

**Recommendation:** **washout = 6°** (top of BRIEF range). Gives 5.4 %
static margin at the design point — within the conventional 5–15 % band,
albeit at the low end. Tip stall margin is healthy at ~10° across the
band; static margin (not stall) is the binding constraint.

Sensitivity at 5° washout across CL (cruise vs slow-flight vs
fast-cruise):

| Design CL | α_trim | SM | α_tip_eff |
|---|---|---|---|
| 0.30 | 4.96° | 7.52 % | +0.73° |
| 0.40 | 6.31° | 5.64 % | +1.18° |
| 0.50 | 7.66° | 4.51 % | +1.63° |
| 0.60 | 9.01° | 3.76 % | +2.08° |
| 0.70 | 10.36° | 3.22 % | +2.53° |

Static margin **decreases with CL**. The high-CL end of the operating
envelope (slow flight, near stall) is the worst case for stability; the
FCS alpha-limiter (mandatory per BRIEF) is the safety-net. At CL = 0.7
with 5° washout, SM = 3.2 % — that's marginal. AVL must confirm.

## CG envelope and pilot mass

For x_CG_trim = 1.053 m (6° washout, design CL = 0.5):

- m_total = m_pilot + 15.5 kg wing + 8.0 kg rig
- x_CG_total = (m_pilot · x_pilot + 15.5 · x_wing + 8.0 · x_rig) / m_total
- For 70 kg pilot, x_pilot ≈ 1.21 m aft of root LE; for 95 kg pilot, x_pilot ≈ 1.16 m
- A ~0.05 m CG-shift envelope across the 70–95 kg pilot range is acceptable;
  this does NOT include the much larger CG perturbation from head/torso
  motion in flight, which is `analysis/flightdynamics/` work and a
  binding constraint on the alpha limiter.

## CAD — `cad/wing/`

The lofted wing surface is generated parametrically from
`analysis/aero/planform/geometry.py`:

- `cad/wing/out/wing.step` — solid for OnShape / Fusion / FreeCAD import.
- `cad/wing/out/wing.stl` — visualization mesh.
- `cad/wing/out/planform_top.png` — top view with MAC and c/4 annotation.

Section is the parametric reflexed placeholder. Drop a real `MH78.dat`
into `cad/wing/airfoils/` and re-run for the production geometry.

## Open issues / verification gates

1. **AVL verification (gating).** Targets in `analysis/aero/avl/README.md`:
   CL_α within ±5 %, NP within ±0.05 MAC, e within physical bounds.
2. **XFOIL polars** for MH 78 and MH 60 across the operational Re sweep.
3. **Cm0 of the actual section** must be ≥ +0.005 — analytic polar has
   that as nominal but with ±0.010 uncertainty.
4. **V_bg vs BRIEF tension** — needs a decision (Path 1/2/3 above)
   before mass and structural budget closes.
5. **Static margin marginal at 5° washout, design CL.** Pin washout at
   6° in `Planform.washout_deg` after AVL confirms the NP location.
6. **High-CL static margin** (CL = 0.7 → SM = 3.2 %): near the lower
   limit. Flight envelope should not extend below CL ≈ 0.65 in trim
   without further analysis; the alpha-limiter target should reflect this.
7. **Pilot CG shift in flight** (head/torso motion) — owned by
   `analysis/flightdynamics/`. The alpha-limiter must close this loop or
   the 3.2–5.4 % static margin band is not enough.

## Reproducibility

```sh
make venv     # one-time setup of .venv with required packages
make aero     # weissinger + trim + glide polar in sequence
make cad      # parametric wing CAD (STEP + STL)
make avl      # optional, requires avl on PATH
make xfoil    # optional, requires xfoil + airfoil .dat
```

All numbers in this doc come from those targets.

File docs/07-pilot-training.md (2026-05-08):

# 07 — Pilot Training Transition

**Status:** First-cut. Defines the syllabus structure and the gate-by-gate
progression from a current fabric-wingsuit pilot to a MANTA-rated pilot.
Tied directly to the test-article progression in
[`docs/06-test-plan.md`](06-test-plan.md).

This addresses BRIEF unsolved-problem #5:

> Pilot training transition path from fabric wingsuit to fly-by-wire
> rigid wing.

A wingsuit pilot, even a very experienced one, does NOT have flight
hours on a fly-by-wire rigid wing. The skill set is genuinely new:
- The vehicle has a stable trim point that the FCS holds; the pilot
  is not constantly fighting body shape to maintain glide.
- The pilot has direct stick / yoke / body-tilt input to flaperons,
  not differential body shape.
- The vehicle has an alpha limiter that **prevents** the pilot from
  pulling into stall — a behavior that's the OPPOSITE of wingsuit
  stall mitigation, where pilot pulls into a flare and accepts the
  drop.
- Reserve deployment is via a wing-jettison-then-reserve sequence,
  not a wingsuit cutaway-and-reserve.

A pilot who carries wingsuit muscle memory into MANTA will:
- Try to pitch the body for trim (fights the FCS).
- Try to hold body-stable into stall (the alpha limiter blocks them).
- Try to deploy reserve before jettisoning the wing (creates a
  fouling case).

The training plan is built to break that muscle memory and replace it.

## Pilot prerequisites

| Requirement | Source |
|---|---|
| Active skydiving rating (USPA A or international equivalent) | Standard prerequisite |
| ≥ 100 wingsuit jumps | Same skill base; not a transferable license but a baseline |
| Current main+reserve+AAD packing within 12 months | Standard skydiving safety |
| Medical (Class 3 or skydiving medical) | Same |
| ≥ 5 hr glider time, dual-rated preferred | Stable-flight intuition |
| Cleared by program safety review for the specific airframe shipset | Program-internal — verifies the pilot has read the BRIEF and the safety case for the version of the vehicle they will fly |

## Transition syllabus

### Phase A — Ground school (~40 hours)

Lecture + simulator + paper.

| Module | Content |
|---|---|
| A.1 Aerodynamic basics | Tailless flying-wing flight characteristics; the static-margin trade; pilot CG perturbation effects (per `analysis/flightdynamics/longitudinal.py`) |
| A.2 FCS architecture | What the alpha limiter does; how mechanical reversion works; sensor fault modes (per `docs/04`) |
| A.3 Deployment sequence | The state machine, every gate, every abort path. Memorize the cockpit display interpretation for each phase (per `docs/03`) |
| A.4 Emergency systems | Cutter system, AAD interface, manual abort handle; reserve compatibility considerations (per `docs/05`) |
| A.5 PX4 SITL simulator | Hands-on with the closed-loop simulator from a representative mock cockpit. Practice handling QUALITIES but not yet real flight |
| A.6 Failure modes | Walk through every entry in `safety/fmea.md`; the appropriate response for each |
| A.7 Practical assessment | Written exam covering all six modules; passing required to advance |

### Phase B — Tow article (manned tow, no in-flight deploy)

Pilot flies the MANTA wing assembly in its deployed configuration,
towed behind a vehicle (slow at first) or boat. The deployment event
is excluded; the pilot only experiences the deployed-wing flight
characteristics.

| Card | What it builds | Gate to advance |
|---|---|---|
| B.1 Static ground hold + control surface check | Familiarization with stick / yoke / body-tilt response | Pilot completes 5 cards with no anomalies |
| B.2 Low-altitude tow (< 5 m AGL), short duration | Pilot maintains tow line tension without porpoising | Pilot rates Cooper-Harper ≤ 4 |
| B.3 Step-up tow altitude | Pilot maintains stable trim at increasing altitude | Same |
| B.4 Release at altitude into a known glide | Pilot transitions from tow to free flight without overshoot | Cooper-Harper ≤ 4 across release configurations |
| B.5 Slow flight characterization | Pilot flies at low V; alpha limiter kicks in; pilot experiences and recognizes the saturation feel | Pilot consistently respects the limit feedback without "fighting" it |
| B.6 Asymmetric-control demonstration | Differential flaperon for roll authority | Roll rate matches predicted; pilot smooth on inputs |
| B.7 Mechanical reversion mode | FCS power deliberately removed; pilot flies on the manual cable | Cooper-Harper rating documented; ≥ 5 minutes successful flight |
| B.8 Reserve descent rehearsal | Deliberate jettison at safe altitude over water; reserve descent and landing | At least 3 successful reserve descents |

### Phase C — Manned exit, deployed (cold release)

Tow up to altitude, release into a stable glide. The pilot exits
the cold-release fixture (no deployment event) and flies the
deployed wing to landing.

| Card | What it adds | Gate |
|---|---|---|
| C.1 First cold-release exit | Exit dynamic on top of deployed flight | Successful flight to landing; no anomalies |
| C.2 Cold-release at higher altitudes | Familiarization with longer glides | Same |
| C.3 Cold-release with deliberate alpha-limiter activation | Pilot demonstrates respect for the limiter in real flight | Pilot rates the experience consistent with simulator |
| C.4 Cold-release with sensor-fault injection | Pilot operates in degraded mode (AoA-fault, etc.) | Pilot maintains control; reserve descent if cued |

### Phase D — Manned exit, deploy-in-flight

The full operational profile. Pilot exits aircraft (or BASE object),
deployment sequence executes, pilot flies under the deployed wing.

**Entry gate:** Phases A, B, C all complete; independent program-level
go/no-go review; AAD verified; recovery procedures rehearsed.

| Card | What it adds | Gate |
|---|---|---|
| D.1 First in-flight deploy | The actual deployment event | Successful deploy + trim acquisition + landing |
| D.2 Subsequent in-flight deploys | Familiarization with deploy variability | Pilot rates qualitative consistency with prior deployments |
| D.3 Asymmetric-deploy abort drill | Forced asymmetric deploy (controlled by FCS injection) | Jettison fires; reserve descends to landing |
| D.4 Drogue-mal abort drill | Forced drogue mal | Same |
| D.5 Operational envelope expansion | Flights to expand the V envelope, the alpha envelope, the altitude envelope | Each flight stays within demonstrated envelope; CHQ ≤ 4 |

## Recurrency

After phase D rating, pilot maintains currency by:

- Minimum 4 flights per quarter
- Phase B equivalent (tow / cold-release) refresher every 12 months
- Re-do the simulator and ground school A.6 (failure modes) every
  24 months
- Any extended layoff > 90 days requires a re-qualification flight
  in phase C before phase D operations

## Open issues

- The simulator (A.5) is not yet built. Need PX4 SITL with the
  MANTA-specific flight dynamics + FCS modules + a representative
  cockpit interface. Significant SW effort before this phase can run.
- Cooper-Harper rating in mechanical reversion (B.7) is an unknown.
  If poor, B.7 becomes a "demonstrate jettison capability before
  HQ becomes unworkable" exercise rather than a "fly in reversion
  for 5 minutes" exercise.
- AAD vendor selection affects card D.3 — different AADs have
  different forced-trigger interfaces. Spec the cards once vendor
  is locked.
- Pilot input device — yoke, stick, or body-tilt sensor — affects
  A.5 simulator and B.1+ control surface check. Whatever is selected
  needs to be the same across the syllabus and the production fleet.

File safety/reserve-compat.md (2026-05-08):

# Reserve parachute compatibility

**Status:** Constraints defined; geometric clearances bracketed; bench
verification + drop-article verification gated as the BRIEF's hardest
constraint.

This document is the closure of the BRIEF's hardest constraint:

> Reserve parachute compatibility is non-negotiable. The skydiving rig
> functions normally for canopy flight and landing after wing jettison.
> Anything that compromises that is a non-starter.

## Hard requirements

The reserve canopy must deploy cleanly **on every credible failure path**
that gets to a reserve event:

1. **Pre-jettison harness geometry** must not interfere with the reserve
   container, ripcord, RSL, or AAD function.
2. **Jettison must remove the wing assembly cleanly.** No hanging spars,
   no flapping skin, no bridle entanglement.
3. **Post-jettison stub geometry** must leave the reserve canopy
   inflation envelope unobstructed.
4. **Reserve deployment trajectory** must be clear — pilot chute
   extraction, bag launch, line stretch, canopy inflation all in
   uncongested air.
5. **Worst-credible attitude case at jettison** (asymmetric-deploy
   induced roll, pilot in unusual attitude) must still allow clean
   reserve deployment.
6. **AAD compatibility:** the AAD signals jettison directly (FCS-bypassed)
   and operates as a standard skydiving AAD when the wing is gone.
7. **Canopy descent and landing**: the wing-harness mount, after
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

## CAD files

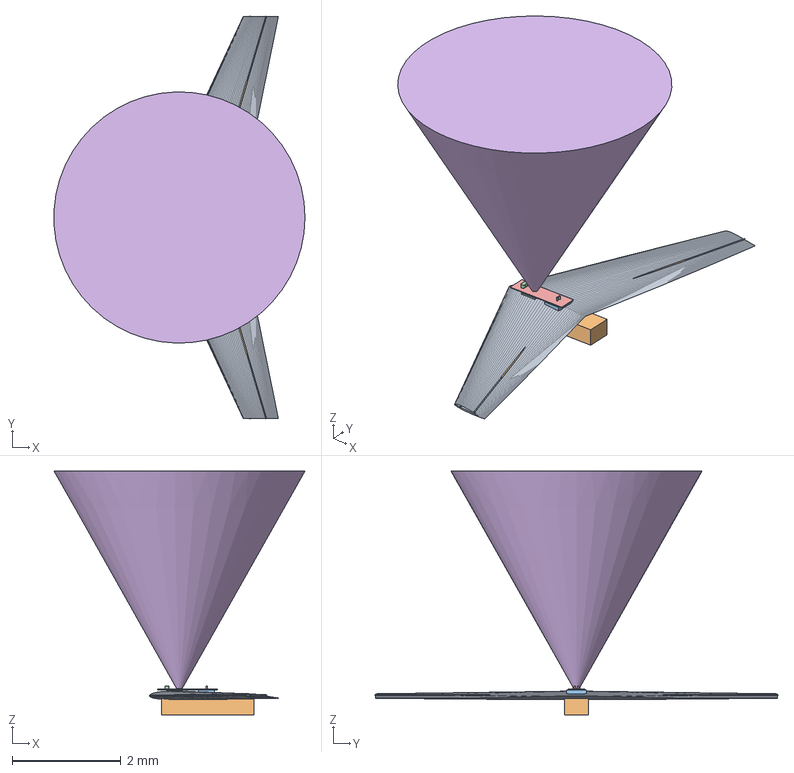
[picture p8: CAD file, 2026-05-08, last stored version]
cad/integration/out/full_assembly_with_cone.step
4.61 x 7.41 x 4.48 mm

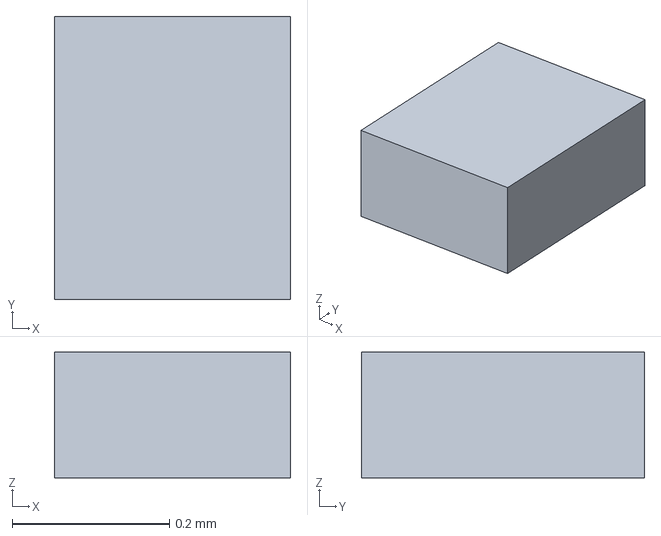
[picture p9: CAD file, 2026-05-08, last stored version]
cad/integration/out/parts/rig_main.step
0.3 x 0.36 x 0.16 mm

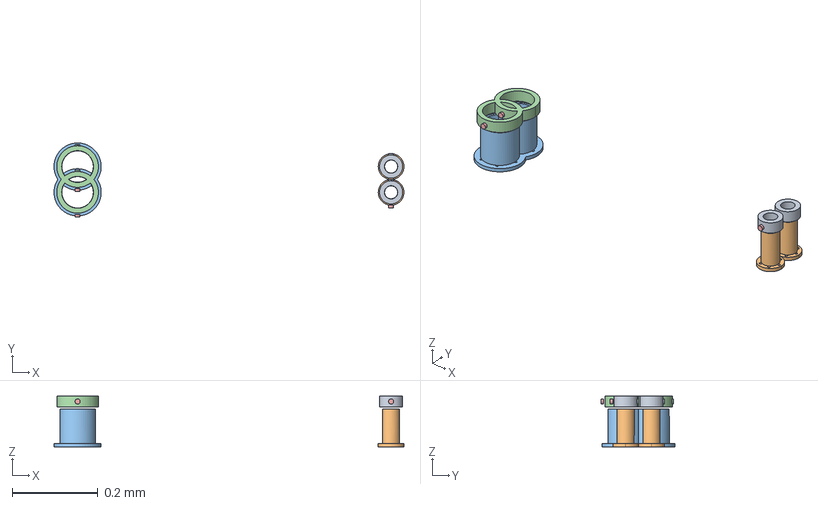
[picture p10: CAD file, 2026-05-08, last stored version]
cad/jettison/out/full_set.step
0.815 x 0.172 x 0.118 mm

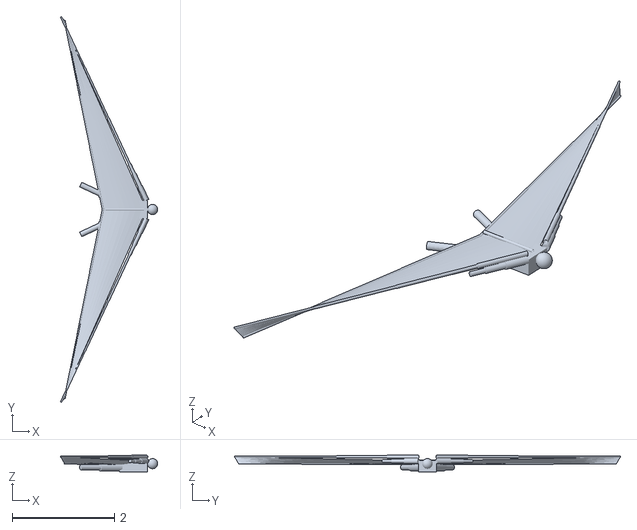
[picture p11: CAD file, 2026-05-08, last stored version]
cad/out/full_deployed.stl
1.91 x 7.57 x 0.327

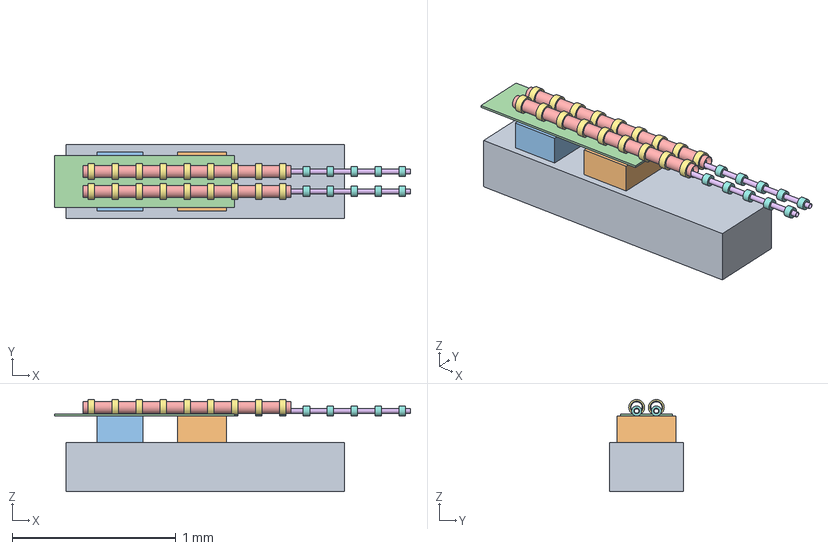
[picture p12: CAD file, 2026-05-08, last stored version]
cad/stowed/out/stowed_assembly.step
2.17 x 0.45 x 0.562 mm

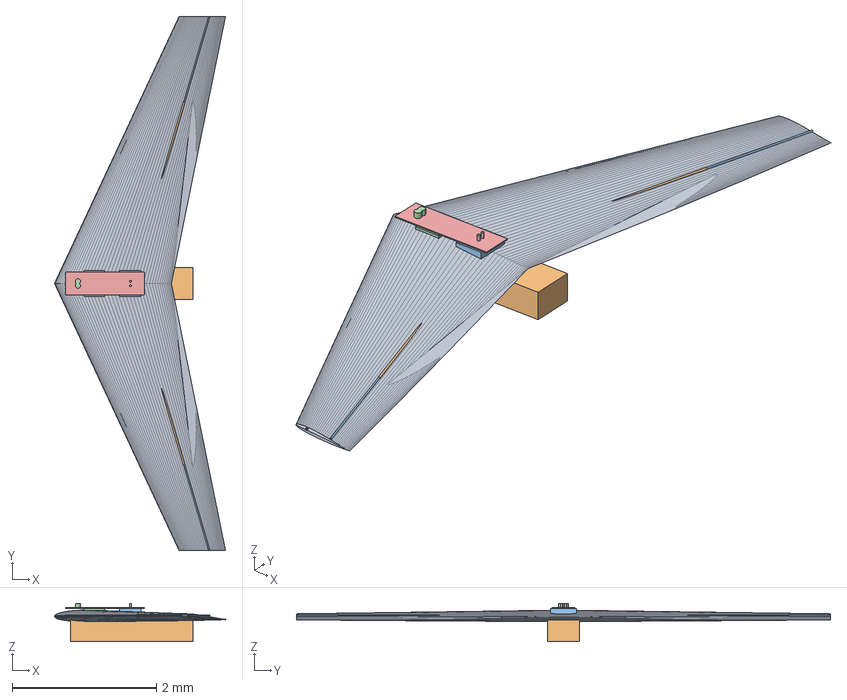
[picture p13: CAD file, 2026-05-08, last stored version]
cad/integration/out/full_assembly.step
2.37 x 7.41 x 0.532 mm

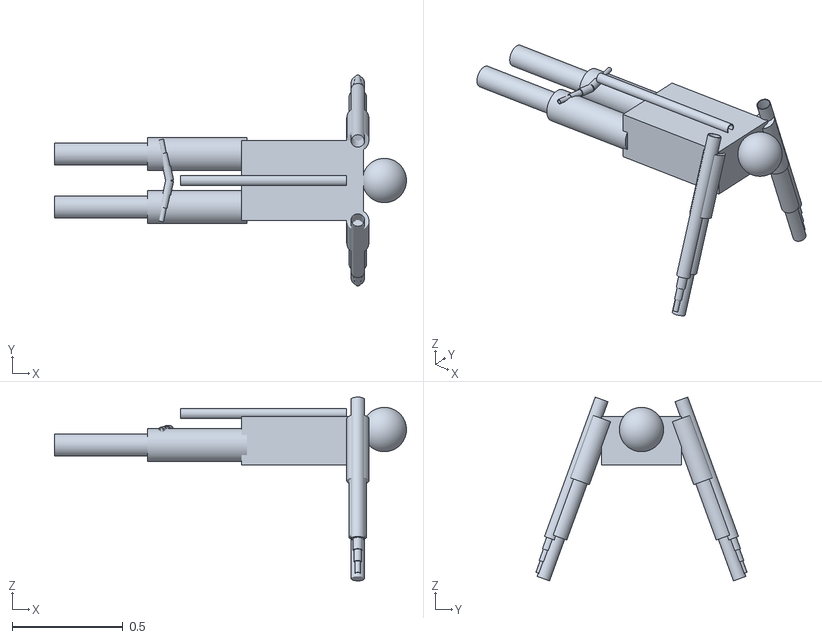
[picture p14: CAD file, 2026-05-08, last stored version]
cad/out/full_stowed.stl
1.59 x 0.954 x 0.83

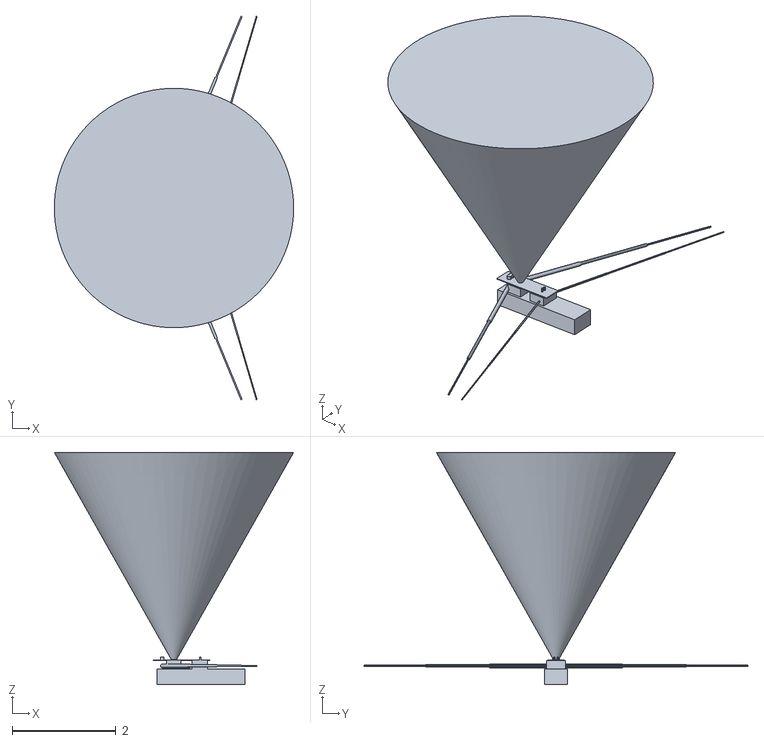
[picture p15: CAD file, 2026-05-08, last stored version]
site/public/models/full_assembly_with_cone.stl
4.62 x 7.41 x 4.48

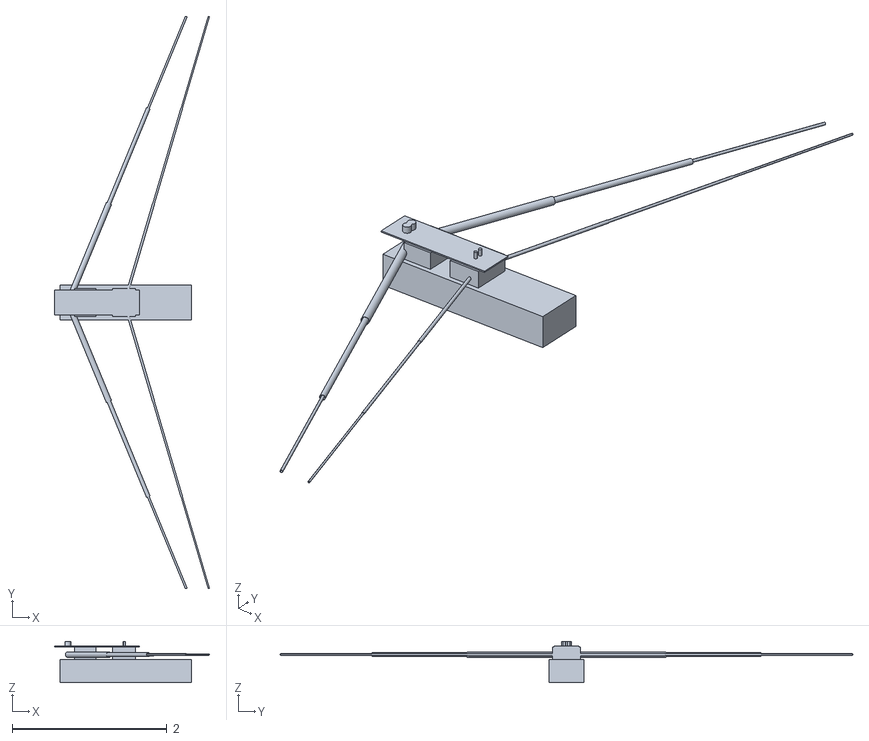
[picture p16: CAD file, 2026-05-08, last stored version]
site/public/models/full_assembly.stl
2.01 x 7.41 x 0.532

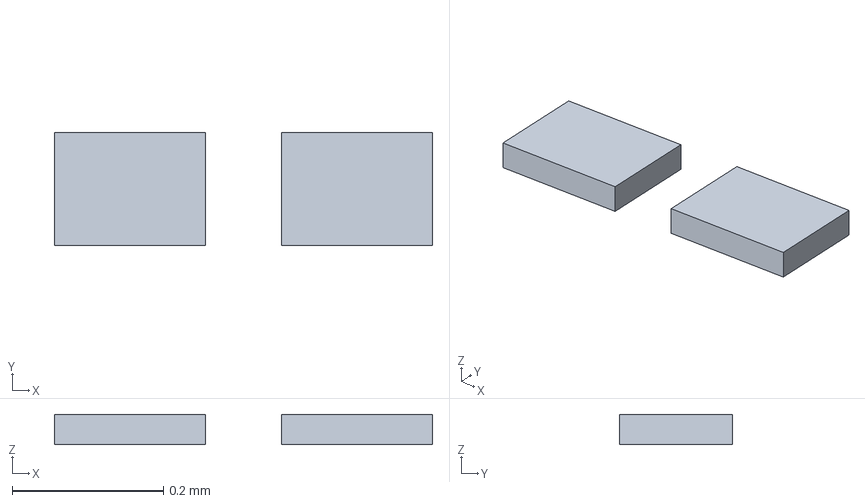
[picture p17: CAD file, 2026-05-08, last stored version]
cad/fcs/out/fcs_bay.step
0.5 x 0.15 x 0.04 mm

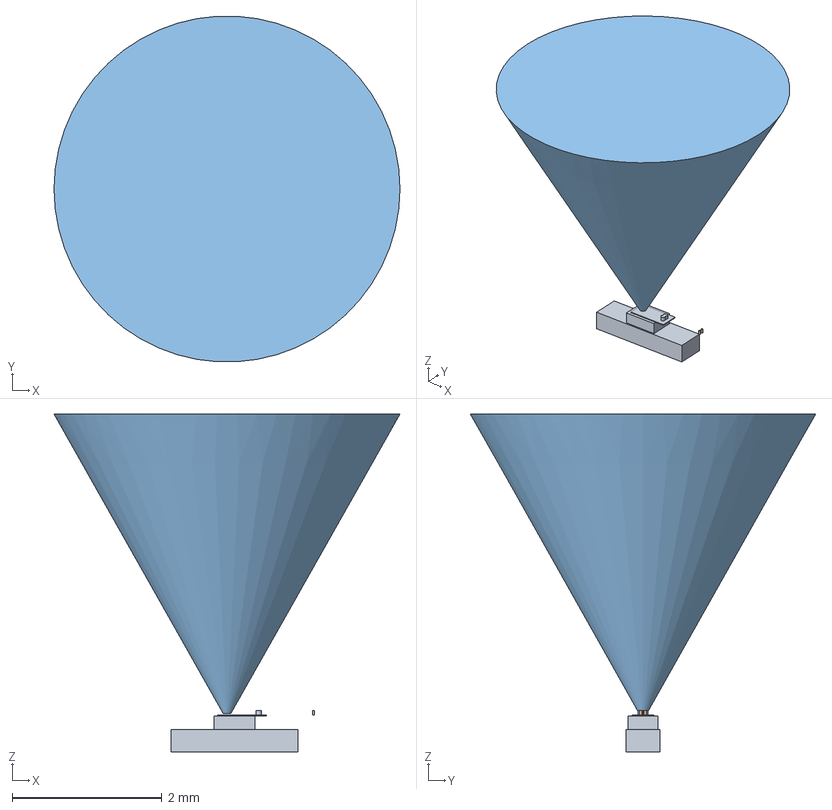
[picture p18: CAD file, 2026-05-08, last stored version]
cad/harness/out/integration_with_cone.step
4.62 x 4.61 x 4.51 mm

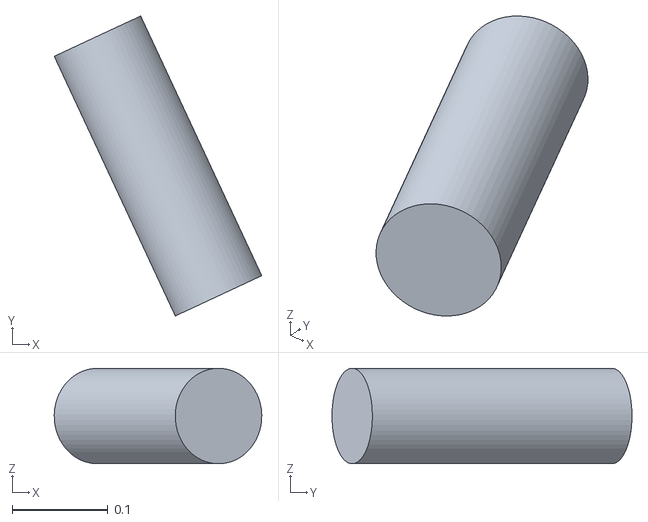
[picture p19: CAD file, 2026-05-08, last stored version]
cad/out/parts/deployed/upper_arm_right.stl
0.217 x 0.314 x 0.0999

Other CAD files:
cad/stowed/out/parts/rig_main.stl
site/public/models/parts/rig_main.stl
site/public/models/stowed/full.stl
site/public/models/stowed/rig_main.stl
cad/fcs/out/fcs_bay.stl
cad/fcs/out/fcs_with_sensors.step
cad/fcs/out/fcs_with_sensors.stl
cad/harness/out/integration.step
cad/harness/out/integration.stl
cad/harness/out/integration_with_cone.stl
cad/harness/out/reserve_cone.step
cad/harness/out/reserve_cone.stl
cad/integration/out/full_assembly.stl
cad/integration/out/full_assembly_with_cone.stl
cad/integration/out/parts/front_spar.step
cad/integration/out/parts/front_spar.stl
cad/integration/out/parts/pilot.step
cad/integration/out/parts/pilot.stl
cad/integration/out/parts/rear_spar.step
cad/integration/out/parts/rear_spar.stl
cad/integration/out/parts/reserve_cone.stl
cad/integration/out/parts/rig_main.stl
cad/integration/out/parts/rig_reserve.step
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

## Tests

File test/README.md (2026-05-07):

# test/

Test article specifications. Pairs with `docs/06-test-plan.md`.

## Progression (no skipping)

| Stage | Path | Gate to pass |
|---|---|---|
| Bench / component | (within `analysis/`) | Component data feeding into the rig design. |
| Ground deployment rig | [`ground/`](ground/) | **200 cycles symmetric within 10 ms 3-σ, no intervention, full thermal/humidity envelope.** |
| Tow article | [`tow/`](tow/) | Trim, stability, control authority, envelope protection demonstrated, deployed-on-tow only. |
| Drop article | [`drop/`](drop/) | End-to-end deploy + jettison + reserve verified, no human aboard. |
| Manned tow | (test plan extension) | Handling qualities acceptable, recovery procedures rehearsed. |
| Manned exit, deployed | (test plan extension) | Towed exit at altitude, released into known glide. |
| Manned exit, deploy-in-flight | (test plan extension) | Full operational profile. After all prior gates + separate go/no-go review. |

## Per-article README

Each test article subdirectory carries its own `README.md` with:

- Article description and scope.
- Instrumentation list.
- Test cards (one per run condition).
- Success and abort criteria.
- Site requirements.
- Linked safety review.

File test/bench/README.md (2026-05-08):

# Bench characterization tests

These run BEFORE the ground deployment rig (`test/ground/`) and feed
the analyses with real input distributions instead of engineering
estimates.

Each bench article is self-contained: it characterizes one component
or one phenomenon, the data it produces gets plugged back into the
analysis it supports, and the analysis re-runs to update its
predictions.

## Articles

| # | Article | Characterizes | Feeds | Spec |
|---|---|---|---|---|
| B1 | Pyrotechnic cutter coupon | LSC + initiator no-fire/all-fire margins, EMI immunity, cut quality | `safety/failure-modes/cutter-no-fire.md`, `safety/failure-modes/cutter-inadvertent-fire.md` | [`b1-cutter.md`](b1-cutter.md) |
| B2 | Drogue ringslot | Inflation profile, bridle snatch peak, dynamic amplification, body-axis stability | `analysis/deployment/drogue_dynamics.py` | [`b2-drogue.md`](b2-drogue.md) |
| B3 | Tape-spring rib snap | Per-rib unfurl time + force trace, dispersion across temperature | `analysis/deployment/symmetry_budget.py` (CONTRIBUTORS row 4), `cad/ribs/build.py` | [`b3-rib-snap.md`](b3-rib-snap.md) |
| B4 | Spar telescope friction | Stage friction vs. T, RH, and water/ice ingress; lock latency distribution | `analysis/deployment/symmetry_budget.py` (row 3), `safety/failure-modes/joint-water-ice-ingress.md` | [`b4-spar-friction.md`](b4-spar-friction.md) |
| B5 | CO2 cartridge variance | Mass-flow vs. T per cartridge lot, distribution of fill mass, regulator behavior | `analysis/deployment/symmetry_budget.py` (row 0), `safety/failure-modes/co2-cold-underpressure.md` | [`b5-co2-cartridge.md`](b5-co2-cartridge.md) |
| B6 | Microswitch latency | Hardware close-to-GPIO-read latency per switch type | `docs/03-deployment-sequence.md` (≤ 1 ms requirement) | [`b6-microswitch-latency.md`](b6-microswitch-latency.md) |
| B7 | Skin tension + bond | DCF skin tear strength, rib-bond peel strength after thermal cycling | `analysis/struct/components.py` skin model | [`b7-skin-bond.md`](b7-skin-bond.md) |
| B8 | Spar root joint | Bonded fitting + cutter interface under combined bending + cutter load | `analysis/struct/spar_bending.py` (root joint FEA gate) | [`b8-root-joint.md`](b8-root-joint.md) |

## Per-article spec template

Each `b*.md` follows this structure:

1. **Purpose** — what this characterizes and why
2. **Article** — physical fixture description; what's representative,
   what's simplified vs. flight hardware
3. **Test cards** — per-condition runs with sample sizes and
   environmental brackets
4. **Instrumentation** — sensors, sample rates, acceptance criteria
5. **Output format** — CSV / HDF5 schema for the data the article
   produces; how it gets plugged back into the analysis
6. **Pass / fail per card** — what closes a card vs. what triggers
   a failure-investigation
7. **Cost / schedule estimate** — to inform program planning

## Why bench-before-rig

The ground deployment rig (`test/ground/`) uses a complete wing
assembly. That's expensive and slow. Bench articles are cheap and
fast, and they de-risk the rig:

- The rig assumes microswitch latency ≤ 1 ms. If B6 shows the
  selected switch is 3 ms, the architecture changes BEFORE the rig
  is built.
- The rig's symmetry-budget closure depends on the input
  distributions in `analysis/deployment/symmetry_budget.py`. If B3,
  B4, B5 show distributions WIDER than the engineering estimates,
  the rig may fail its 200-cycle gate. Better to know on the bench
  than after a 6-month rig build.
- The rig's first cutter live-fire is the FIRST cutter event in the
  program. B1 confirms cutter behavior on a coupon before any
  cutter is integrated into a wing assembly.

## Schedule

Bench articles are mostly independent of one another and can run in
parallel. Realistic timeline:

| Quarter | Bench articles |
|---|---|
| Q1 | B5 (CO2 cartridge), B6 (microswitch latency) — both fast, low-cost, high-value |
| Q1 | B1 (cutter coupon) — vendor-led, runs in parallel |
| Q2 | B3 (rib snap), B4 (spar friction) — produce the symmetry-budget inputs |
| Q2 | B2 (drogue) — needs a small drop tower or a wind tunnel |
| Q3 | B7 (skin bond), B8 (root joint) — structurally bigger, slower |

By end of Q3 the inputs to the symmetry-budget Monte Carlo have been
measured; the architecture-revision recommendations from
`analysis/deployment/symmetry-budget.md` either close cleanly or
require the bigger architecture change.

## Output retention

All bench data is retained per the same protocol as ground-rig data
(`test/ground/spec.md`): one HDF5 file per cycle / per condition,
indexed by article, condition, and timestamp. Failure-investigation
write-ups under each article's `failure-investigations/` subdirectory.

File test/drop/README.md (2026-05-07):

# test/drop/

Drop article. Ballasted, instrumented, no human on board. Released from an aircraft and executes the full deployment sequence — drogue, wing deploy, optional jettison + reserve scenarios — across the operational speed/altitude envelope.

**Gate to enter:** tow article has demonstrated trim, stability, and control authority within predicted envelopes.

To be populated. The drop article is the first time the full sequence is exercised end-to-end at flight conditions. Comprehensive instrumentation (telemetry + on-board recording) is mandatory.

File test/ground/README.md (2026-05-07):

# test/ground/

Ground deployment rig. **Deliverable #6** in BRIEF — the first piece of MANTA hardware to actually build.

## What it is

A fixture that holds the full wing assembly off the body, with no flight loads, instrumented to characterize and prove the deployment kinematics:

- Cycles deploy → restow repeatably (target: ≥200 cycles before re-build).
- Records left-right deploy timing per stage, both spars.
- Records spar-stage lock confirmations (microswitches).
- Records skin tension at multiple chord stations per side.
- Records valve actuation feedback and CO2 cartridge pressure / temperature.
- Records ambient T and RH; conditions to cold soak / hot / humid extremes.

## Hard gate (BRIEF)

> Do not move to flight-relevant test articles until the ground deployment rig has demonstrated reliable, symmetric, sensed deployment over the full thermal and humidity envelope, in at least 200 cycles without intervention.

## To produce

- `spec.md` — the rig specification: structural fixture, instrumentation, DAQ, environmental conditioning, cycle automation.
- `test-cards/` — per-condition run cards.
- `data-handling.md` — file formats, naming, retention, review process.
- `cad/test-rig/` (yes, the rig itself gets CAD) — fixture and harness.

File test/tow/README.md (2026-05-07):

# test/tow/

Tow article. Wing already deployed before launch; towed behind a boat or vehicle. Verifies aerodynamic predictions, control authority, stall behavior, and envelope-protection effectiveness — without ever requiring an in-flight deploy event.

**Gate to enter:** ground deployment rig has passed its 200-cycle gate.

To be populated. The tow article is structurally identical (or near-identical) to the flight wing but with a tow attachment and instrumentation pack. Stays low and slow during initial test cards; envelope expanded over a planned series.

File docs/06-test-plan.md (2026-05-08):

# 06 — Test Plan

**Status:** First-cut. Defines the progression from bench through manned
deploy-in-flight, with explicit gates that map to the analyses closed in
deliverables #1–#6.

## Overall progression — no skipping

```
       ┌─────────────────┐
       │  bench /        │   component-level: cutters, drogue, snap-springs,
       │  component      │   spar-friction characterization, sensor latency
       └────┬────────────┘
            ▼
       ┌─────────────────┐
       │  ground         │   200-cycle reliability gate per BRIEF;
       │  deployment rig │   the 10 ms 3-σ symmetry gate is verified here
       └────┬────────────┘
            ▼
       ┌─────────────────┐
       │  tow article    │   wing already deployed before launch;
       │                 │   verifies aero predictions, control authority,
       │                 │   envelope protection — without ever needing to
       │                 │   deploy in flight
       └────┬────────────┘
            ▼
       ┌─────────────────┐
       │  drop article   │   ballasted instrumented article released from
       │                 │   aircraft; full deploy + jettison + reserve
       │                 │   sequence; no human aboard
       └────┬────────────┘
            ▼
       ┌─────────────────┐
       │  manned tow     │   first human flights in the deployed wing,
       │                 │   towed launch, no in-flight deploy
       └────┬────────────┘
            ▼
       ┌─────────────────┐
       │  manned exit,   │   towed exit at altitude, released into a known
       │  deployed       │   glide. Avoids the deploy event but adds the
       │  (cold release) │   exit dynamic.
       └────┬────────────┘
            ▼
       ┌─────────────────┐
       │  manned exit,   │   FULL operational profile. After ALL prior
       │  deploy-in-     │   gates pass and a separate program-level
       │  flight         │   go/no-go review.
       └─────────────────┘
```

## Bench / component characterization

These run in parallel with the analysis work and feed empirical numbers
back into the predictions. They are *not* gated; results are inputs to
the ground-rig and downstream gates.

| Article | Purpose | Outputs |
|---|---|---|
| **Pyrotechnic cutter coupon** | No-fire / all-fire margins on the LSC and initiators per shipset. EMI immunity per DO-160. | Vendor cert + program acceptance file |
| **Drogue ringslot** | Inflation profile, snatch load, body-axis stability under representative q. | Time-history trace of bridle load + canopy area |
| **Tape-spring rib snap test** | Per-rib unfurl time and dispersion across temperature. Force trace via instrumented hinge. | Distribution of snap-energy and snap-time |
| **Spar joint friction** | Stage-lock-time variance under thermal + humidity conditioning, water/ice ingress. | Distribution of stage friction force vs. T, RH |
| **Microswitch latency** | Hardware response from physical contact close to FCS GPIO read. ≤ 1 ms requirement. | Per-channel latency distribution |
| **CO2 cartridge variance** | Mass-flow rate vs. temperature, batch-to-batch, ≥ 200 cartridges. | Distribution of effective fill mass and flow rate |
| **Skin tension and bond** | Tear-strength of the rib/spar bond after thermal cycling. | Stress-to-failure of bonded coupons |

Each is a self-contained test plan written when the article is built.
Distributions feed the symmetry-budget Monte Carlo
([`analysis/deployment/symmetry_budget.py`](../analysis/deployment/symmetry_budget.py))
to replace the engineering estimates with measurements.

## Ground deployment rig (deliverable #6)

Specification: [`test/ground/spec.md`](../test/ground/spec.md).

**Gate:** 200 cycles of symmetric, sensed deployment over the full
thermal and humidity envelope, no operator intervention. 3-σ |Δt_LR|
≤ 10 ms across the run.

Conditions and counts:

| Condition | T | Humidity / state | Cycles |
|---|---|---|---|
| Hot/dry | +50 °C | < 20 % RH | 25 |
| Hot/humid | +35 °C | 95 % RH | 25 |
| Nominal | +20 °C | 50 % RH | 50 |
| Cold | −10 °C | dry | 25 |
| Cold/wet | −5 °C | spray-soaked, drained | 25 |
| Cold/iced | −5 °C | spray-soaked, frozen | 25 |
| Re-test in nominal | +20 °C | 50 % RH | 25 |
| **Total** | | | **200** |

Failure-investigation protocol per [`test/ground/spec.md`](../test/ground/spec.md):
no "ran it again, it worked" closures.

Pre-gate also: the **first cutter live-fire on a complete wing assembly
in the program** happens here, in a controlled test cell. The 200-cycle
deploy gate uses the FCS-mediated mechanical-only deploy-restow path;
cutter firings are a separate, single-shot test campaign on the same
fixture.

## Tow article (no in-flight deploy)

Article: structurally representative wing assembly, pre-deployed and
secured open, towed behind a vehicle (vehicle tow at low speed for
initial cards) or boat (extended speed envelope).

**Gate to enter:** Ground-rig 200-cycle gate passed.

Test cards:

| Card | What it shows | Pass criteria |
|---|---|---|
| Static tow at low speed | Trim alignment with prediction | CL_α matches Weissinger ±10 % |
| Speed envelope sweep | L/D vs V across operational range | Curve shape matches prediction; (L/D)_max within ±15 % of nominal |
| Slow-flight characterization | α_stall location and stall character | Gentle stall, no abrupt rolloff |
| Alpha-limiter activation | Limiter holds α at limit when commanded into stall | No departure |
| Pilot-CG-perturbation simulation | Ballast shifted at altitude on the tow boom | Recovery within 5 s; no departure |
| Asymmetric-control demonstration | Differential flaperon command produces predicted roll rate | Roll rate matches AVL prediction |
| Gust ingestion | Tow through a marked turbulent area | Pilot rates handling qualities Cooper-Harper ≤ 4 |

**Gate to exit:** Trim, stability, control authority within predicted
envelopes. Envelope protection demonstrated under realistic disturbances.
Cooper-Harper ≤ 4 across the operational envelope.

## Drop article (no human; full sequence)

Article: ballasted instrumented test article in the wing-and-harness
configuration, released from a chase aircraft at altitude. Executes the
full deploy sequence including drogue, wing deploy, and (in
deliberately-induced abort cases) jettison + reserve.

**Gate to enter:** Tow article passed all cards.

Test cards:

| Card | What it shows | Pass criteria |
|---|---|---|
| Nominal deploy at design speed | Full sequence executes per `docs/03` | All states transitioned in budget; trim acquired |
| Cold-condition deploy | Conditioned article deploys nominally | Same |
| Asymmetric-deploy abort (induced) | One side delayed by 30 ms; abort fires | Jettison fires within 75 ms of detection; reserve clears stubs |
| Drogue-mal abort | Drogue PC deliberately disabled | Bypass-and-jettison logic fires; reserve inflates clean |
| AAD-induced abort | AAD altitude trigger forced | Wing departs ahead of reserve; reserve inflates clean |
| Spar-lock-fail abort | One lock sensor disconnected | Timeout fires; jettison + reserve |
| Reserve compatibility (asymmetric) | Asymmetric-deploy + jettison + reserve in worst-credible attitude | Reserve inflates; no fouling on stubs |

**Gate to exit:** End-to-end sequence verified; jettison + reserve clean
across all credible failure modes. Drop-article has been recovered
intact across the full envelope.

## Manned tow

First human flight. Towed launch, deployed wing only — no in-flight
deploy.

**Gate to enter:** Drop article all-cards-passed. Pilot transition
training plan in place. Pilot rated for skydiving + tow operations.

Test cards (progression, NOT a single article):

1. Static ground hold + control surface check
2. Low-altitude tow (1 m AGL), short duration
3. Step-ups in altitude and speed
4. Release at altitude into a known glide
5. Reserve-canopy descent rehearsal (deliberate jettison at safe
   altitude over water with retrieval boat)

**Gate to exit:** Pilot rates handling qualities acceptable across the
flight envelope. Recovery procedures rehearsed. Reserve descent
configurations verified for canopy phase.

## Manned exit, deployed (cold release)

Tow up to altitude, release into a stable glide, fly to landing under
the wing. Avoids the deploy event entirely.

**Gate to enter:** Manned tow passed. Independent program-level go/no-go
review.

This adds the exit-from-aircraft dynamic and the unpowered glide phase
without the deployment risk.

## Manned exit, deploy-in-flight

The full operational profile per BRIEF: pilot exits aircraft (or BASE
object), deployment sequence executes, pilot flies under the deployed
wing.

**Gate to enter:** ALL prior gates passed, AND a separate
program-level go/no-go review with:
- Independent failure-mode review
- Updated FMEA reflecting all test data
- Pilot proficiency in all prior phases
- Range / site approvals
- Recovery procedures rehearsed in real conditions
- AAD interface integration verified

This is the first time the deploy-in-flight event has a human in the
loop. It is irreducibly the highest-risk event in the program. Treat
the gate-to-enter as binding.

## Range / site requirements

| Article | Site requirement |
|---|---|
| Bench | In-house lab with range-rated EMI and pressure capabilities |
| Ground rig | Lab with environmental conditioning chamber, instrumented test bay; ≥ 10 m vertical clearance for tip-swing |
| Tow article | Open water (boat tow) or long airfield runway (vehicle tow); chase boat / chase truck |
| Drop article | Drop range with telemetry coverage; chase aircraft for release; recovery boat / recovery vehicle |
| Manned tow | Open water; drop zone with reserve-landing area downwind |
| Manned exit | Skydiving operation drop zone; chase aircraft; AAD-rated reserve packing |

## Schedule (representative)

The following is a representative critical path. Adjust as analyses and
hardware bench tests update predictions.

| Quarter | Activity |
|---|---|
| Q1 | Bench / component characterization; cutter vendor pick; CO2 cartridge data |
| Q2 | Ground rig fabrication; first nominal-condition runs |
| Q3 | Ground rig 200-cycle gate (full envelope) |
| Q4 | Tow article fabrication |
| Y2 Q1 | Tow article test campaign |
| Y2 Q2 | Drop article fabrication; first nominal drop |
| Y2 Q3 | Drop article asymmetric-deploy + reserve verification |
| Y2 Q4 | Manned tow campaign |
| Y3 Q1 | Manned cold-release flights |
| Y3 Q2 | Manned deploy-in-flight (first) |

This is a research-aircraft schedule; it slips when the gates don't
close cleanly. The program does not skip ahead.

## Reproducibility

Each article carries its own `test/<article>/` subdirectory with:

- `spec.md` — what the article is and what it measures
- `cards/` — per-card test sheets
- `data/` — retained data files, indexed by cycle/run number
- `failure-investigations/` — closed-out write-ups for any anomaly

Already populated: [`test/ground/spec.md`](../test/ground/spec.md). Tow,
drop, manned-tow, and manned-exit articles get specs as the program
reaches them.

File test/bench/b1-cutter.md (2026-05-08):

# B1 — Pyrotechnic cutter coupon test

**Purpose:** Quantify pyrotechnic cutter behavior on a representative
spar root coupon BEFORE any cutter is integrated into a flight
article. Closes the no-fire / all-fire / EMI gates from
`safety/failure-modes/cutter-no-fire.md` and `cutter-inadvertent-fire.md`
on bench data, not just vendor cert.

## Article

A short length of CFRP tube matching the front-spar root OD (73 mm OD,
2.5 mm wall, sized config) bonded into an aluminum cup of the
production fitting geometry. The cutter assembly wraps the tube just
outboard of the bond region, exactly as in the flight configuration.

Initial article quantity: 4 (one per shipset of cutters tested), with
provision for replacements.

## Cards

| Card | Condition | Samples | Pass criteria |
|---|---|---|---|
| 1.1 | No-fire margin: 1 W / 1 A applied to initiator for 5 minutes; verify no fire | 10 cutters | 10 / 10 no-fire |
| 1.2 | All-fire margin: 3.5 A pulse, 50 ms duration; verify fire within spec | 10 cutters | 10 / 10 fire within timing window |
| 1.3 | EMI immunity per RTCA DO-160 G H — 200 V/m HIRF, lightning Cat A direct + Cat B indirect | 4 cutters | No fire under any condition |
| 1.4 | ESD immunity — 5 kV, 500 pF model on initiator pins | 4 cutters | No fire |
| 1.5 | Cold soak fire — cutter conditioned to −20 °C, then fire at the cold-soak temp | 4 cutters | Fire within timing spec; clean cut |
| 1.6 | Hot soak fire — +50 °C | 4 cutters | Same |
| 1.7 | Cut quality on a representative bonded spar root | 8 cutters | Severance complete; no spar-end fiber wisps; ferrule retains cut end |
| 1.8 | Dual-initiator independence | 4 cutters | Single initiator fires alone successfully (no degradation) |
| 1.9 | Vibration survival per DO-160 Cat S | 4 cutters | No degradation; no inadvertent fire under vibration |

## Instrumentation

- Cutter firing-circuit voltage and current at 100 kHz sample rate
- High-speed video at ≥ 1000 fps of the cutter and the spar end
- Thermocouple on the cutter housing
- Force transducer on the spar (verifies a complete cut releases the
  spar without residual mechanical resistance)

## Output format

```
test/bench/data/B1-{card}/{cutter_serial}_{condition}.csv
   columns: t_us, V_firing, I_firing, force_N, T_housing_C
```

Plus video files referenced by cycle id.

## Pass / fail per card

A failure on any card stops B1 progression and triggers a failure-
investigation write-up. Card 1.7 (cut quality) is the binding card for
flight integration — without clean cut quality demonstration the
cutter cannot be integrated into a flight article.

## Cost / schedule

Cutter coupons + spars: ~$2k each shipset of 10 cutters → ~$8k for
the full B1 campaign.
EMI lab access: ~$5k for 1 day; cards 1.3 + 1.4 batched into one day.
Cold/hot soak: lab climate chamber, 1 day.
Total: ~$15k materials + lab fees, ~3 weeks calendar time.

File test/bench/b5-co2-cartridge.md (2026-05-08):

# B5 — CO2 cartridge variance characterization

**Purpose:** Measure mass-flow rate and fill mass distribution per
cartridge across the operational temperature envelope, and per cartridge
lot. The dominant contributor to the symmetry budget is CO2 cartridge
variance (10.6 ms 3-σ in
[`analysis/deployment/symmetry_budget.py`](../../analysis/deployment/symmetry_budget.py)),
modeled with σ = 2.5 ms. B5 is the measurement that confirms or
tightens that engineering estimate.

## Article

Bench fixture that holds a single 88 g CO2 cartridge against a
pressure regulator and discharge valve, with the regulator output
plumbed to a calibrated sonic-orifice flow meter. The cartridge is
fired and the regulator pressure / mass-flow trace is captured.

For per-side variance studies, two fixtures run in parallel from a
common arm signal so that the differential between two cartridges
under nominally identical conditions can be measured directly.

## Cards

| Card | Condition | Samples | What it measures |
|---|---|---|---|
| 5.1 | +20 °C nominal, single fixture | 50 | Reference fill-mass distribution |
| 5.2 | +30 °C, +20 °C, 0 °C, −10 °C, −20 °C — single fixture | 25 each | Mass-flow vs. temperature curve per cartridge |
| 5.3 | +20 °C, dual-fixture differential | 50 pairs | Per-side σ_t differential at room temp |
| 5.4 | −10 °C, dual-fixture differential | 25 pairs | Per-side σ_t at the cold operational floor |
| 5.5 | Cartridge lot-to-lot variance | 50 cartridges from each of 3 lots | Lot-level σ; informs whether lot-segregation procedure is needed |
| 5.6 | Heater-on cold environment | 25 pairs at −10 °C ambient with cartridges held at +20 °C | Heater performance — does the cartridge deliver +20 °C performance under cold ambient |

## Instrumentation

- Pre-fire mass via load cell (measures cartridge dry mass; full vs. empty difference = fill mass)
- Cartridge T (thermocouple on cartridge body, +/−0.5 °C)
- Regulator output P at 10 kHz
- Mass-flow rate via sonic-orifice meter at 10 kHz
- Total discharge time
- Ambient T, RH

## Output format

```
test/bench/data/B5-{card}/{lot_id}/{cartridge_serial}.csv
   columns: t_ms, mass_flow_g_per_s, P_regulator_bar, T_cartridge_C
```

Plus per-cartridge metadata file with fill mass, manufacturer cert,
lot id.

## Pass / fail per card

For card 5.4 — the cold-soak differential — the gate is **σ_t < 4.0 ms
3-σ between the two fixtures**. A wider distribution forces option A
(shared reservoir) to be adopted to common-mode the cartridge variance.

## Output to the analysis pipeline

The measured σ_t per condition replaces the engineering-estimate value
in `analysis/deployment/symmetry_budget.py`:

```python
CONTRIBUTORS = (
    Contributor("CO2 cartridge fill mass / temp",
                sigma_ms=<measured>,    # was 2.5; replace with B5 result
                common_mode_fraction=<0.0 for option-A=False, 0.85 for option-A=True>),
    ...
)
```

Re-run the Monte Carlo with the empirical sigma. If the budget closes
at the target architecture, the bench has done its job.

## Cost / schedule

50 + 5×25 + 50 + 25 + 150 + 25 = 425 cartridge fires. Cartridge cost
~$1 each → $425. Bench fixture build ~$8k. Climate chamber rental ~$3k
for 2 weeks. Lab time at 20 fires/day → ~3 weeks.
Total: ~$12k, ~4 weeks.

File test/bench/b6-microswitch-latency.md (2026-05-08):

# B6 — Microswitch latency characterization

**Purpose:** Verify hardware close-to-GPIO-read latency on the
selected spar-lock microswitch. The deployment-sequence specification
([`docs/03-deployment-sequence.md`](../../docs/03-deployment-sequence.md))
requires ≤ 1 ms latency on every lock-sensor channel — without this,
the asymmetric-deploy detector cannot resolve the 10 ms 3-σ symmetry
budget. B6 is the one-day bench test that confirms or rejects each
candidate switch part.

## Article

A single microswitch + GPIO interface board. The switch is mounted
in a fixture that drops a calibrated impactor onto its actuator from
a known height; an accelerometer on the impactor captures the contact
event, and a separate GPIO logger captures the FCS-equivalent register
read. The two are time-aligned at 100 kHz sample rate.

This is one of the cheapest, fastest bench tests in the program. Run
it FIRST when the switch is selected, before the part gets specified
into the harness wiring.

## Cards

| Card | Switch condition | Samples | Pass criteria |
|---|---|---|---|
| 6.1 | Nominal, fresh switch | 200 | ≤ 1 ms latency on 95 % of trials |
| 6.2 | After 10,000 mechanical cycles | 100 | Same; no degradation |
| 6.3 | At −10 °C | 50 | ≤ 1 ms (some grease may stiffen at cold) |
| 6.4 | At +50 °C | 50 | Same |
| 6.5 | After exposure to spray-water and drainage | 50 | No false closures, latency unchanged |
| 6.6 | Bounce / contact chatter characterization | 100 | Bounce duration documented; firmware debounce strategy chosen |

## Instrumentation

- Impactor accelerometer (charge-mode, 100 kHz)
- GPIO logger / oscilloscope on the switch contact line (100 kHz)
- Drop fixture with adjustable impactor mass and height (energy
  matched to the actual rib unfurl impulse delivered to the lock pin)

## Output format

```
test/bench/data/B6-{card}/{switch_serial}/trial_{nnn}.csv
   columns: t_us, accel_g, gpio_state
```

Per-trial latency = (time of first GPIO transition) − (time of
accelerometer peak ≥ contact threshold).

## Pass / fail per card

A switch that fails B6 cannot be the production part. Switch
selection iterates until B6 passes, typically across 2–3 candidates.

## Output to the analysis pipeline

If the selected switch shows latency > 1 ms typical, the symmetry
budget tightens by that amount per side. The contributor in
[`analysis/deployment/symmetry_budget.py`](../../analysis/deployment/symmetry_budget.py)
is currently 0.8 ms (valve port differential) which assumes < 1 ms
sensor latency. A 3 ms switch latency adds ~3 ms 3-σ to that
contributor and pushes the budget out by ~3 ms 3-σ overall — a
significant change.

## Cost / schedule

Switches: ~$50 each for industrial-grade aerospace parts; 5 candidate
parts × 5 each = ~$1250.
Drop fixture build: ~$2k.
Lab time: 1–2 days per candidate.
Total: ~$5k, ~2 weeks.

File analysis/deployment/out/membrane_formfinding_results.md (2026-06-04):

# Skin membrane form-finding — deployment into a controlled surface

The deployed skin is a pretensioned membrane stretched over the bistable ribs; the telescoping booms + rib snap put it in tension. Bay sag (the waviness off the design airfoil) follows from membrane statics `δ = q·s²/(8·N)`, cross-checked by discrete relaxation.

| Quantity | Value |
|---|---|
| Cruise dynamic pressure q | 211 Pa |
| Net skin pressure (cruise / 3 g) | 158 / 475 Pa |
| Skin pretension (deployment-set) | 2200 N/m |
| Bay spacing (rib pitch) | 266–266 mm |
| **Worst bay sag @ 3 g** | **1.9 mm** |
| **Surface waviness δ/c @ 3 g** | **0.27 %** (within the 0.4 % tol) |
| Skin stays in tension (no wrinkles) | yes |
| Billow fraction handed to the 3D model | 0.015 |

**Result.** With the deployment putting ~2200 N/m of pretension into the skin, the worst inter-rib sag is ~1.9 mm even at the 3 g limit — a surface waviness of 0.27 % chord, within the 0.4 % aero tolerance. So the deployed wing is a smooth, controlled airfoil (and a clean trailing-edge flaperon), NOT a billowing canopy. The earlier 14 %-of-thickness 'billow' was ~10× too large for a rigid pretensioned skin; the model now uses the physical 0.015.

The pretension is itself a deployment requirement: the booms and the bistable rib snap must deliver it for the surface to come out fair — linking the deployment mechanism to the final aerodynamic quality.

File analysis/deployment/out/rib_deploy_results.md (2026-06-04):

# Bistable rib deployment — reduced-order physics

Strain-energy-driven unroll of a bistable rolled-composite rib (thin-ply HSC carbon, lenticular section). Backs the `rib_unroll` geometry in `sim/build.py`.

| Quantity | Value |
|---|---|
| Shell wall t | 0.14 mm |
| Coil radius r_coil | 11.0 mm |
| Coil strain ε = t/2R | 0.64 % (< ~1 % HSC allowable) |
| Shell rigidity D | 18.09 mN·m |
| Propagation moment M\* | 2.14 mN·m |
| Driving force F_drive = M\*/r | 195 mN |
| Rib chord (representative) | 1.00 m |
| Rib mass ρ·L | 22 g |
| **Snap time t_snap (s→0.99)** | **692 ms** |
| Peak deploy velocity | 1.98 m/s |
| **Latch-contact velocity** | **1.96 m/s** (soft) |
| End-latch shock | 27 N |
| Passive friction hold / drive | 0.13× (insufficient) |

**Deployment.** Each ~1.0 m rib snaps from packed coil to latched airfoil in ~692 ms, driven by the constant Seffen–Pellegrino propagation force F = M\*/r_coil = 195 mN. The 9 ribs/side fire on a root→tip stagger, so the unfurl front sweeps outboard across Phase C — this is the schedule the `rib_unroll` animation renders (`RIB_STAGGER`, `RIB_SNAP_DUR`).

**Soft latch.** A rotary viscous damper on the hub bleeds the stroke so the rib reaches its end-stop at only 1.96 m/s, keeping the deployment-shock load to ~27 N — well under the 0.2 N the latched root carries — so there is no destructive snap.

**Blossoming guard (design driver).** Inter-layer friction alone holds only 0.13× the steady tip force, i.e. it is **insufficient**: a free friction coil WOULD blossom (unwind loosely inside the deployer). That is exactly why the hub is a **rate-controlled spool** (the same viscous damper): it meters payout so the coil feeds the front under tension instead of blooming. Bistable end-detents then hold both the stowed and the deployed states without a restraint band.

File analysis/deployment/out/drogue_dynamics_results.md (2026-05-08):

# MANTA drogue dynamics

  Total mass for sizing: 105.0 kg (sized-config wing)
  Terminal V (no drogue): 55.0 m/s (BRIEF reference)
  Target V after drogue:  30.0 m/s
  Pilot CdA (prone):      0.4 m²
  Drogue CD (ringslot):   0.55

## Sizing — drogue area required to produce target equilibrium descent

  CdA_total required at V = 30.0 m/s:  1.868 m²
  CdA_drogue (subtracting pilot):                 1.468 m²
  Drogue area (A = CdA / C_D):                    2.669 m²
  Drogue diameter (round canopy):                 1.843 m

## Snatch load + deceleration

  Peak bridle tension:    3944 N  (3.94 kN)
    occurs at t = 0.445 s, V = 51.0 m/s
    dynamic amplification factor: 1.7

  Time to V ≤ 31 m/s: 4.66 s

## Snatch vs. flight loads

  Pilot weight (1 g):           1030 N  (1.00 g)
  3 g limit flight:             3089 N  (3.00 g)
  4.5 g ultimate flight:        4634 N  (4.50 g)
  **Drogue snatch peak**:       3944 N  (3.83 g)

  ⚠ Drogue snatch exceeds 3 g limit flight load. The harness mount has to be sized to this case rather than 3 g flight.

## Where does this load go?

  Drogue bridle attaches to the **harness**, NOT the spar roots.
  The wing is still stowed when the drogue is loaded; the spars
  do not see the snatch load directly in the nominal sequence.

  Coupling cases that DO put drogue tension on the spars:
  - Asymmetric deploy with drogue still attached: brief
    cross-coupling via the bound wing-harness interface.
    Bounded by the ground-rig data once that exists.
  - Drogue-cut-release with one cutter not firing: drogue
    drag asymmetry into the deployed wing. Mitigated by
    redundant drogue release.

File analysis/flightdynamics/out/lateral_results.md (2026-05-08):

# MANTA lateral-directional flight dynamics

## Trim at V = 16.0 m/s,  CL = 0.782

Stability derivatives (rad⁻¹ unless noted):
  Cl_β  = -0.1349   (dihedral effect; <0 stable, sweep contrib)
  Cl_p  = -0.5420   (roll damping; <0 stable)
  Cl_r  = +0.2292   (roll-from-yaw)
  Cn_β  = +0.0200   (yaw stiffness; >0 stable)  ⚠ tailless
  Cn_p  = -0.0977   (yaw-from-roll)
  Cn_r  = -0.0184   (yaw damping; <0 stable)  ⚠ tailless
  CY_β  = -0.0500   (side-force; <0 stable)

Modes:
  Dutch roll:  λ = -0.6930+2.2924jj   ω_n = 2.395 rad/s (0.381 Hz)   ζ = +0.289   T = 2.74 s
               handling-quality: Level 2 (acceptable)
  Roll mode:   λ = -15.6544+0.0000j     τ = +0.064 s
  Spiral mode: λ = +0.0459+0.0000j     τ = -21.810 s  (DIVERGENT)
               time-to-double = 15.1 s

## Trim at V = 20.0 m/s,  CL = 0.500

Stability derivatives (rad⁻¹ unless noted):
  Cl_β  = -0.0864   (dihedral effect; <0 stable, sweep contrib)
  Cl_p  = -0.5420   (roll damping; <0 stable)
  Cl_r  = +0.1287   (roll-from-yaw)
  Cn_β  = +0.0200   (yaw stiffness; >0 stable)  ⚠ tailless
  Cn_p  = -0.0625   (yaw-from-roll)
  Cn_r  = -0.0262   (yaw damping; <0 stable)  ⚠ tailless
  CY_β  = -0.0500   (side-force; <0 stable)

Modes:
  Dutch roll:  λ = -0.6080+2.2650jj   ω_n = 2.345 rad/s (0.373 Hz)   ζ = +0.259   T = 2.77 s
               handling-quality: Level 2 (acceptable)
  Roll mode:   λ = -20.2715+0.0000j     τ = +0.049 s
  Spiral mode: λ = +0.0086+0.0000j     τ = -115.961 s  (DIVERGENT)
               time-to-double = 80.4 s

## Trim at V = 25.0 m/s,  CL = 0.320

Stability derivatives (rad⁻¹ unless noted):
  Cl_β  = -0.0553   (dihedral effect; <0 stable, sweep contrib)
  Cl_p  = -0.5420   (roll damping; <0 stable)
  Cl_r  = +0.0644   (roll-from-yaw)
  Cn_β  = +0.0200   (yaw stiffness; >0 stable)  ⚠ tailless
  Cn_p  = -0.0400   (yaw-from-roll)
  Cn_r  = -0.0311   (yaw damping; <0 stable)  ⚠ tailless
  CY_β  = -0.0500   (side-force; <0 stable)

Modes:
  Dutch roll:  λ = -0.6814+2.4627jj   ω_n = 2.555 rad/s (0.407 Hz)   ζ = +0.267   T = 2.55 s
               handling-quality: Level 2 (acceptable)
  Roll mode:   λ = -25.6620+0.0000j     τ = +0.039 s
  Spiral mode: λ = -0.0124+0.0000j     τ = +80.824 s  (stable (convergent))

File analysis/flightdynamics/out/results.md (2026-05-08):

# MANTA longitudinal dynamics

Trim:  V = 16.00 m/s,  CL = 0.782,  CD = 0.0650
       α_trim = 11.74°,  CL_α = 4.285/rad
       static margin = 3.45 % MAC
       Iyy = 25.0 kg·m², MAC = 1.205 m

State-space A:
[[-0.102  -0.27   -9.8066  0.    ]
 [-1.2258 -3.3598 16.      0.    ]
 [ 0.     -0.5871 -8.3621  0.    ]
 [ 0.      0.      1.      0.    ]]

Eigenvalues + modes:
  oscillatory  λ = -5.7984+1.4483jj   ω_n = 5.976 rad/s (0.951 Hz)   ζ = 0.970   period = 4.34 s
  real         λ = +0.0000+0.0000j    τ = +inf s
  real         λ = -0.2271+0.0000j    τ = +4.403 s

## CG offset sweep — pilot head/torso shift

| Δx_CG (m) | SM (% MAC) | short-period ω_n (rad/s) | ζ_sp | phugoid ω_n | ζ_ph | Status |
|---|---|---|---|---|---|---|
| -0.050 | -0.70 | n/a | n/a | n/a | n/a | UNSTABLE |
| -0.030 | +0.96 | n/a | n/a | n/a | n/a | UNSTABLE |
| -0.020 | +1.79 | n/a | n/a | n/a | n/a | UNSTABLE |
| -0.010 | +2.62 | 5.829 | +0.999 | n/a | n/a | STABLE |
| +0.000 | +3.45 | 5.976 | +0.970 | n/a | n/a | STABLE |
| +0.010 | +4.28 | 6.125 | +0.943 | n/a | n/a | STABLE |
| +0.020 | +5.11 | 6.274 | +0.918 | n/a | n/a | STABLE |
| +0.030 | +5.94 | 6.423 | +0.894 | n/a | n/a | STABLE |
| +0.050 | +7.60 | 6.719 | +0.851 | n/a | n/a | STABLE |

Pilot CG perturbation context:
  Pilot mass fraction of total: 78.6%
  ±50 mm shift of upper-body CG → ±39.29 mm shift of vehicle CG
  → ±3.26 % of MAC

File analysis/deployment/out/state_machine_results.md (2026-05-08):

# Deployment state machine — nominal scenario

Final state: GLIDE
Abort cause: NONE
Drogue extract t : 2.005
Wing deploy cmd  : 4.6000000000000005
Wing locked t    : 5.05
Glide acquired   : 5.055

State trace:
  t= 0.000s  →  ARMED   (pilot arm)
  t= 0.700s  →  FREEFALL   (freefall dwell met)
  t= 2.000s  →  STABILIZE   (stable freefall)
  t= 2.005s  →  DROGUE_INFLATING   (drogue extract cmd)
  t= 4.595s  →  DROGUE_STABLE   (drogue stable)
  t= 4.600s  →  WING_DEPLOY   (wing deploy cmd)
  t= 5.050s  →  WING_TRIM_ACQUIRE   (wing locked, Δt = 5.00 ms)
  t= 5.055s  →  GLIDE   (trimmed glide)

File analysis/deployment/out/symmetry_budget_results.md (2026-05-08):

# MANTA deployment symmetry budget — Monte Carlo

## Contributors

| Contributor | σ (ms) | common-mode fraction | 3-σ contribution to Δt (ms) |
|---|---|---|---|
| CO2 cartridge fill mass / temp | 2.50 | 0.00 | 10.64 |
| Valve port differential | 0.80 | 0.00 | 3.40 |
| Manifold flow impedance match | 1.50 | 0.00 | 6.33 |
| Spar telescope friction (cold / wet) | 2.00 | 0.00 | 8.50 |
| Tape-spring snap dispersion (per-rib summed) | 1.20 | 0.00 | 5.10 |

## Combined  (50,000 trials)

  3-σ |Δt|   :  **16.25 ms**
  P99  |Δt|  :  13.94 ms
  P99.9 |Δt| :  17.98 ms
  max |Δt|   :  23.38 ms

  vs BRIEF gate (10.0 ms 3-σ): **FAIL** (margin = -6.25 ms)

## Sensitivity sweep — 3-σ of |Δt| as each contributor scales

| Contributor | scale | 3-σ |Δt| (ms) | vs nominal |
|---|---|---|---|
| CO2 cartridge fill mass / temp | 0.5× | 13.32 | -2.92 |
| CO2 cartridge fill mass / temp | 1.0× | 16.19 | -0.06 |
| CO2 cartridge fill mass / temp | 2.0× | 24.53 | +8.29 |
| Valve port differential | 0.5× | 15.91 | -0.34 |
| Valve port differential | 1.0× | 16.19 | -0.06 |
| Valve port differential | 2.0× | 17.24 | +0.99 |
| Manifold flow impedance match | 0.5× | 15.16 | -1.09 |
| Manifold flow impedance match | 1.0× | 16.15 | -0.09 |
| Manifold flow impedance match | 2.0× | 19.60 | +3.36 |
| Spar telescope friction (cold / wet) | 0.5× | 14.42 | -1.83 |
| Spar telescope friction (cold / wet) | 1.0× | 16.19 | -0.06 |
| Spar telescope friction (cold / wet) | 2.0× | 21.85 | +5.61 |
| Tape-spring snap dispersion (per-rib summed) | 0.5× | 15.72 | -0.53 |
| Tape-spring snap dispersion (per-rib summed) | 1.0× | 16.31 | +0.06 |
| Tape-spring snap dispersion (per-rib summed) | 2.0× | 18.53 | +2.28 |

## Closing the budget — alternate architectures

If the nominal architecture cannot close, what alternates do?

| Option | 3-σ |Δt| (ms) | vs gate (10.0 ms) | Status |
|---|---|---|---|
| A — shared CO2 reservoir (common-mode 0.85) | 12.86 | -2.86 | FAIL |
| B — active per-side flow modulation (all σ × 0.5) | 8.11 | +1.89 | PASS |
| C — mechanical-spring primary, CO2 unlock only | 10.12 | -0.12 | FAIL |

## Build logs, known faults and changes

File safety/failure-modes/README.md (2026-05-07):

# safety/failure-modes/

Per-failure-mode write-ups. Each file: detection, mitigation, response, residual risk, test evidence.

## Naming

`{subsystem}-{short-name}.md` — e.g. `asymmetric-deployment.md`, `cutter-no-fire.md`, `reserve-fouling.md`.

## Priority queue

In rough order of severity × likelihood, populate:

1. `asymmetric-deployment.md` — dominant unrecoverable failure mode per BRIEF. First file written here.
2. `cutter-no-fire.md` — pyrotechnic spar-root cutter fails to fire on jettison command.
3. `cutter-inadvertent-fire.md` — cutter fires when it shouldn't.
4. `reserve-fouling.md` — reserve canopy or lines snag on residual wing structure.
5. `alpha-limiter-loss.md` — envelope protection lost or saturated.
6. `joint-water-ice-ingress.md` — telescoping joint binding from environmental contamination.
7. `co2-cold-underpressure.md` — cartridge insufficient at low ambient T.
8. `sensor-dropout.md` — primary sensor fails; per-channel analysis.
9. `aad-fault.md` — AAD interface fault.
10. `drogue-mal.md` — drogue malfunction.
11. `reversion-fault.md` — mechanical reversion path unavailable.

Each file links back to its row in `safety/fmea.md`.

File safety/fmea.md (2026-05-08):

# FMEA — Failure Mode and Effects Analysis

**Status:** Top failure modes populated from the analyses closed in
deliverables #1–#6. Living document — every architecture decision change
or new analysis result updates the relevant rows. Per-mode write-ups
under [`safety/failure-modes/`](failure-modes/) carry the detail and the
verification gates.

## Severity scale

| Severity | Definition |
|---|---|
| Catastrophic | Loss of vehicle and / or pilot fatality |
| Hazardous | Substantial reduction in safety margin or pilot ability to handle adverse conditions |
| Major | Significant reduction in safety margin; substantially increases workload |
| Minor | Small reduction in safety margin; impairs ability to perform normal mission |

## Top failure modes

| ID | Subsystem | Failure mode | Cause(s) | Severity | Likelihood (post-mit) | Detection | Mitigation | Test evidence required |
|---|---|---|---|---|---|---|---|---|
| `FM-DEP-001` | deployment | [Asymmetric wing deployment](failure-modes/asymmetric-deployment.md) | CO2 fill variance, manifold imbalance, spar friction, snap dispersion | Catastrophic | ≤ 0.3 % per deploy (option-B arch) | Per-side spar-lock Δt + roll-rate divergence | Active per-side flow modulation (option B); jettison + reserve on detection | Ground rig 200-cycle gate; drop article asymmetric-deploy demonstration |
| `FM-DEP-002` | deployment | Drogue malfunction | Drogue PC misfire, drogue inversion, bridle snag | Catastrophic | < 0.1 % per deploy | Drogue load cell < 50 % within 4 s + accel signature | Bypass drogue → jettison if airworthy; pilot reserve | Drop article — drogue-mal scenario; bench drogue inversion characterization |
| `FM-STR-001` | structures | Spar root failure under flight load | Bending overload, bond defect, fatigue | Catastrophic | < 10⁻⁶ per flight | Skin tension load cells (advisory); pilot perception of flutter | Bending-sized spar (73 mm OD, 2.5 mm wall, SF 1.5 at 3 g limit); FEA of root joint; coupon tests of bonded layup | Static load test of full root assembly; FEA correlation |
| `FM-CUT-001` | jettison | Pyrotechnic cutter no-fire | Initiator dud, LSC defect, electrical fault | Catastrophic | < 10⁻⁵ per cutter (B-basis) | Cutter-fired-OK signal absent within 50 ms | Dual initiators per cutter; redundant firing circuits; manual reserve as final fallback | LSC vendor coupon tests; integrated cutter-firing tests at the drop article |
| `FM-CUT-002` | jettison | Pyrotechnic cutter inadvertent fire | Static, EMI, lockout failure, software bug | Catastrophic if airborne; major if on ground | < 10⁻⁷ per cutter operating hour | (Detection is lockout monitoring) | Two-stage arming (mechanical lockout + electrical arm); inhibits while the deployment SM is in pre-deploy state; AAD signal independent path | Lockout cycle test; EMI immunity test (military-style HIRF / lightning); first-fire on ground rig only |
| `FM-RSV-001` | reserve | Reserve canopy fouling on jettison stub | Stub geometry too large, severed-fiber snag, bridle wrap | Catastrophic | < 10⁻⁴ per jettison | (Detection is post-failure; mitigation is preventive) | Stub geometry verified clean of reserve cone in CAD + bench mock-up; rounded ferrule on cut spar; drop article verification | [`safety/reserve-compat.md`](reserve-compat.md) gates 1–6 |
| `FM-FCS-001` | FCS | Alpha-limiter loss | Both FCS units fault; AoA vane + airspeed both fail; software bug | Hazardous | < 10⁻⁵ per flight | FCS health monitor; sensor-fault EKF flags | Triplex IMUs; redundant FCS units; degraded-mode α estimate; mechanical reversion if FCS unrecoverable; pilot procedure: jettison + reserve > 200 m AGL | Sensor-fault scenario in PX4 SITL; HIL test of degraded modes |
| `FM-FCS-002` | FCS | EKF divergence in trim acquisition | Sensor noise, magnetic deviation, GNSS dropout at exit | Major | < 10⁻³ per flight | EKF residual monitor; cross-check between FCS-A / FCS-B / aux IMU | EKF tuning per environment; magnetometer calibration on every aircraft; GNSS-degraded fallback to ground-speed proxy | SITL Monte Carlo across exit conditions |
| `FM-PIT-001` | pitch stability | Pilot CG perturbation pushes wing into negative SM | Postural change in flight; gust-induced pilot motion | Hazardous | ~ 1 in 10² flights (un-mitigated) | EKF body-rate divergence; α nearing limit | Alpha limiter mandatory; pitch damper in the inner loop; harness restraints to limit pilot torso travel; pilot training | Closed-loop SITL across CG-shift envelope; wind-tunnel or tow-test verification |
| `FM-JNT-001` | spars | Telescoping joint binding (water/ice ingress) | Sub-zero ambient, rain on jump run, condensation | Major (fails to deploy on one or more stages) | Unknown — ground-rig characterization gate | Per-stage lock sensor doesn't latch within timeout | Sealed joints (lip seals + drainage), thermal conditioning of stowed assembly, pre-flight check after exposure | Ground rig cold/wet/iced conditioning runs (25 cycles each per [`test/ground/spec.md`](../test/ground/spec.md)) |
| `FM-CO2-001` | pneumatics | CO2 cartridge under-pressure (cold) | Sub-zero ambient or stored cartridge | Catastrophic if it causes asymmetric deploy or no-deploy | Bound by `FM-DEP-001` mitigation (option B) | Per-cartridge T + P sensor pre-firing | Heated cartridges OR shared CO2 reservoir + Option B; pre-flight check | Ground rig cold-condition firings |
| `FM-AAD-001` | safety | AAD fault | Electronics failure, dead battery, mis-armed | Hazardous | ~ 10⁻⁵ per flight (skydiving baseline) | Built-in self-test pre-flight | Production-grade AAD with current cert; pre-flight self-test mandatory; pilot-initiated reserve always available | AAD cert + integration test |
| `FM-DRG-001` | drogue | Reserve canopy descent obstructed by harness mount | Mount geometry not optimized for canopy phase | Major (slow descent rate, hard landing) | < 10⁻³ per landing | Pilot perception under canopy | Harness mount geometry verified for canopy descent; flight-test under reserve; pilot-rated landing-speed envelope | First-cut: `safety/reserve-compat.md`; later: drop article + manned-canopy rehearsal |
| `FM-RVR-001` | mech reversion | Mechanical reversion path blocked / fouled | Cable routing chafe, internal interference with deployed wing | Hazardous | < 10⁻⁴ per flight | Pre-flight functional check; reversion-mode entry test once per pre-flight | Routing analysis; pre-flight check in deployed-mock-up configuration; pilot procedure: jettison + reserve if reversion fails | First-cut: `cad/fcs/` routing study; later: bench reversion test |

## Progression / interconnections

These rows are not independent. The dominant chain is:

```
   FM-CO2-001 → FM-DEP-001 → FM-RSV-001 (if jettison stub fouls reserve)
                       ↓
                  FM-CUT-001 (if cutters don't fire on the asymmetry)
                       ↓
                  pilot manual reserve (last fallback)
```

Mitigation of `FM-DEP-001` (the dominant case) cascades downstream — the
better the symmetry budget closes, the less reliance on the
jettison-and-reserve chain.

## What the BRIEF rule "would this hold up if a coroner asked for it"
means in this context

For each row above, the program needs:
1. The cited test data exists and is documented.
2. The mitigation is in the as-built hardware and software, not just on paper.
3. The independence of redundancy paths is verified, not assumed.
4. Failure investigations from any test campaign are closed before
   moving on (no "ran it again, it worked").

Until all rows have completed verification gates, the residual-risk
likelihoods are predictions, not measurements.

## To populate next

Per-mode write-ups in [`failure-modes/`](failure-modes/) for the rows
above that don't yet have one. Priority: `FM-CUT-001`, `FM-CUT-002`,
`FM-RSV-001`, `FM-AAD-001`, `FM-FCS-001`, `FM-JNT-001`.

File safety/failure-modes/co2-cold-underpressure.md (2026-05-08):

# Failure mode: CO2 cartridge under-pressure (cold)

**FMEA ID:** `FM-CO2-001`
**Severity:** Catastrophic if it causes asymmetric deploy or no-deploy
**Pre-mitigation likelihood:** ~10⁻² per flight at T < 0 °C, < 10⁻⁴ at T > +20 °C (single cartridge per side)
**Post-mitigation likelihood:** Bound by `FM-DEP-001` mitigation (option B + shared reservoir + active modulation)

## What it means

CO2 cartridge mass-flow rate depends on the cartridge's internal
pressure, which is set by its temperature (vapor pressure of CO2 at
ambient T). Cold cartridges flow significantly less mass per second:

| Cartridge T | Vapor pressure | Effective mass-flow rate (relative to +20 °C) |
|---|---|---|
| +30 °C | ~71 bar | 1.05× |
| +20 °C | ~57 bar | 1.00× (reference) |
| 0 °C | ~35 bar | ~0.85× |
| −10 °C | ~26 bar | ~0.75× |
| −20 °C | ~19 bar | ~0.65× |

Below ~−15 °C the regulator may not be able to maintain the working
pressure for the full deploy duration, even on a fresh cartridge. The
two failure sub-cases:

| Sub-case | Consequence |
|---|---|
| Both cartridges run out of pressure before stages lock | Wing partially deploys; stage-lock-fail timeout fires jettison + reserve |
| One cartridge underflows asymmetrically (the colder one or the leaker) | Asymmetric Δt > 10 ms gate; jettison + reserve |
| Both cartridges underflow symmetrically | Slow-deploy on both sides; may still complete within the 0.5 s wing-deploy timeout, but with reduced energy and possible partial lock |

## Detection

- **Cartridge T + P telemetry** before fire — sensors at each cartridge
  read T and (via the regulator) starting pressure. The FCS pre-flight
  check refuses to arm if either cartridge is below the operational
  threshold.
- **Manifold pressure trace during fire** — the ground rig measures
  this; in flight the FCS records it but doesn't gate on it (too late).
- **Stage-lock progression** — the abort logic catches the downstream
  consequences (asymmetric, no-lock, lock timeout).

## Mitigation chain

The dominant mitigation is at the symmetry-budget architecture level
(per [`analysis/deployment/symmetry-budget.md`](../../analysis/deployment/symmetry-budget.md)):

1. **Shared reservoir (option A)** — the per-cartridge variance becomes
   common-mode and cancels in Δt, so a cold-batch cartridge can't
   produce asymmetric flow. CdA budget closes from CO2 contribution
   10.6 ms 3-σ to ~3 ms.
2. **Active per-side flow modulation (option B)** — closed-loop sensing
   of stage-lock progress modulates per-side flow. If both sides are
   underflowing symmetrically (cold-soak), the FCS can decide the deploy
   is no longer credible and abort to jettison + reserve before either
   side completes (preventing partial deploy).
3. **Combined A + B** — both architectural changes together. This is
   the recommended end-state for the program.

In addition:

4. **Heated cartridges.** Each cartridge has a small resistive heater
   (~2 W) that maintains it at +20 °C from arm to fire. Battery cost
   is small; mass cost ~30 g per cartridge.
5. **Operational envelope discipline.** No flight at ambient T < −10 °C
   until the ground rig demonstrates the 200-cycle gate at the next-
   colder temperature with no failures. The envelope grows with
   demonstrated reliability.
6. **Cartridge pre-flight check.** Each cartridge's T + P verified
   before the wing assembly is stowed. Out-of-spec cartridges are
   replaced. Fresh cartridges sourced from a single batch with traceable
   lot numbers.
7. **Cartridge installation procedure.** Riggers install fresh
   cartridges per shipset; cartridges are NOT carried on the aircraft
   between flights at low ambient T.

## Residual risk

After mitigation:

- **Heated cartridge fails** during a cold flight (heater open or
  power lost): residual is the un-heated case, which the option-B
  active-modulation handles. ~10⁻⁴ per flight.
- **Operational-envelope discipline fails** (pilot dispatches outside
  envelope): procedural-discipline residual; ~10⁻⁴ per flight assumes
  a properly trained operator and rigger sign-off.
- **Cartridge actual T + P deviate from datasheet** (manufacturing
  defect): ~10⁻⁵ per cartridge; pre-flight T + P check catches most.

## Verification gates

| Gate | What it shows | Where |
|---|---|---|
| Cartridge mass-flow vs. T | Each lot characterized over operational T range | Bench |
| Heater system test | Cartridge holds +20 °C in −10 °C ambient with 2 W draw | Bench |
| Cartridge T + P sensor calibration | Sensors read accurately to within 0.5 °C and 1 bar | Bench |
| Shared-reservoir test | Common-mode CO2 effect verified — single bottle drives two outlets | Bench |
| Active-modulation test | FCS modulates valve flow based on simulated stage-lock-progress sensor input | Bench HIL |
| Ground-rig cold-condition runs | 200-cycle gate at the cold-conditioned envelope | [`test/ground/spec.md`](../../test/ground/spec.md) |

## Open issues

- Heater design and cartridge mounting. The 2 W heater is a small mass
  but a real wiring change to the harness; needs to be in the FCS bay
  CAD.
- Single-batch cartridge sourcing — operationally enforced, but the
  enforcement is a procedural document that needs to be written
  (ops manual, deferred from this phase).
- Higher-pressure alternative to CO2 (e.g. compressed N₂ at 200 bar):
  trades higher pressure for higher mass and complexity. Not currently
  considered but worth mentioning as an architecture-level fallback if
  CO2 cannot close cold-condition reliability.

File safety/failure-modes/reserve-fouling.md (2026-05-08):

# Failure mode: reserve canopy fouling on residual structure

**FMEA ID:** `FM-RSV-001`
**Severity:** Catastrophic
**Pre-mitigation likelihood:** ~10⁻³ per jettison (uncharacterized stub geometry)
**Post-mitigation likelihood:** < 10⁻⁴ per jettison (CAD-verified geometry, drop-article confirmed)

## What it means

After the four pyrotechnic cutters fire and the wing assembly departs,
short stubs remain at each of the four root fittings (per
[`safety/reserve-compat.md`](../reserve-compat.md)). The reserve
canopy's pilot chute, bag, lines, or the canopy itself can:

- **Snag on a stub** during line-stretch — line wraps an exposed
  spar end with severed-fiber edge.
- **Inflate INTO a stub** — canopy fabric finds itself trapped
  between a stub and clear air.
- **Foul with the bridle** — drogue bridle, if not cleanly released,
  trails through the reserve deployment path.
- **Inflate asymmetrically** because part of the canopy contacts
  residual structure during inflation, producing a streamer or
  partial inflation that does not provide a survivable descent.

Any of those produces a partially-inflated reserve canopy that may not
control descent rate to a survivable landing.

## Detection

This is a **post-failure** mode — by the time fouling is detected, the
canopy is already mis-inflated. Detection is for the program (root
cause analysis after a survivable event) and for the test campaign
(drop article instrumented for it):

- **Pilot perception** under the reserve: hard to characterize at
  ~150–200 m AGL; pilot may have only 5–10 s before ground impact.
- **Drop article telemetry** + on-board video: characterize each
  drop event for inflation cleanliness.
- **Post-flight rigging inspection**: any reserve event that resulted
  in a survivable but non-nominal descent gets a full rigging
  forensic to identify whether residual structure contributed.

## Mitigation chain — preventive

This is dominantly a *preventive* mitigation problem (you don't recover
from fouling once inflation is already going badly):

1. **Stub geometry verified clear of the reserve cone in CAD.** Per
   `cad/harness/build.py` — all 4 stubs are 0.42–1.15 m outboard of
   the 30°-half-angle reserve cone at the apex level. Geometric
   margin documented per shipset.
2. **Rounded ferrule end on each cut spar.** Internal ferrule
   captures the spar end during the LSC cut, leaving a smooth
   metallic terminus rather than a frayed CFRP fiber tip. Vendor
   verification per cutter design.
3. **Drogue bridle cleanly releases with the wing.** The bridle is
   attached at the wing root and cut by a dedicated mechanism (line
   cutter or pyrotechnic) at the wing-stable signal. If the wing
   departs, the bridle goes with it.
4. **Stub orientation in the chord plane only.** No vertical
   projection above the harness shell: stubs are mounted on the
   sub-frame plate, axes parallel to body x-axis. Reserve cone
   opens upward; stubs sit horizontally, far from the cone.
5. **Drop-article verification across the credible attitude
   envelope.** The drop article exercises symmetric, asymmetric, and
   pilot-pulled-tilted reserve deployments. Each one is logged.
6. **Pre-flight visual inspection of the stubs** to verify no damage,
   debris accumulation, or foreign hardware that could change the
   geometry from the verified configuration.

## Mitigation chain — recovery

If a reserve fouling does occur and the pilot is conscious enough to
respond:

- **Cutaway the reserve risers** is NOT possible — most modern reserves
  have no cutaway capability. (Fouling is the reason main-canopy
  cutaway exists; reserves don't have it because the reserve is the
  last canopy.)
- **Manual canopy clearing** — if the pilot can identify a snag,
  pulling the affected line(s) sometimes clears the fouling. This is
  a skill that is rehearsed in skydiving but is not reliable.
- **Ride the partial inflation to terrain** with whatever descent rate
  results. Pilot trains for high-impact landing in this case.

In summary: recovery from reserve fouling is unreliable. The mitigation
strategy is overwhelmingly weighted toward prevention.

## Residual risk

After mitigation:

- **Stub geometry verified but a new shipset has a manufacturing
  error** that pushes a stub into the cone: ~10⁻⁴ per shipset.
  Mitigated by per-shipset CAD-vs-as-built geometry verification.
- **Drogue bridle release fails AND wing fails to depart cleanly**:
  rare combined failure; mitigated by independent failure-paths in
  the bridle release and the cutter system.
- **Reserve canopy itself has a malfunction** (line twist, partial
  inflation) that's NOT caused by MANTA-specific structure: this is
  baseline skydiving residual risk (~10⁻⁴ per skydive), unaffected
  by MANTA mitigation.

## Verification gates

| Gate | What it shows | Where |
|---|---|---|
| CAD clearance check (per shipset) | Stub geometry vs. reserve cone with ≥ 3× margin in all dimensions | [`cad/harness/build.py`](../../cad/harness/build.py) |
| Bench mock-up | Physical geometry agrees with CAD; rigger sign-off | TBD |
| Drop article — symmetric jettison reserve deployment | Reserve clears stubs cleanly at design speed | [`test/drop/`](../../test/drop/) |
| Drop article — asymmetric jettison | Reserve clears stubs in worst-credible attitude | Same |
| Drop article — pilot-induced unusual attitude | Reserve clears stubs from inverted, banked, tumbling | Same |
| Drogue release verification | Bridle clears the wing-departure path | Bench + drop |
| Per-shipset stub geometry inspection | As-built stubs match the CAD-verified configuration to within tolerance | Acceptance |

## Open issues

- The rounded-ferrule cutter design is conceptual — vendor selection
  pending.
- Reserve-line-clearing pilot training has not been formalized into
  the MANTA pilot transition syllabus (`docs/07-pilot-training.md`
  TBD).
- Drop-article instrumentation for fouling characterization is heavier
  than the standard drop article — needs additional cameras and on-
  board recording. Spec'd as part of [`test/drop/spec.md`](../../test/drop/) when written.

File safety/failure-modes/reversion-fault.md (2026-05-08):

# Failure mode: mechanical reversion path blocked or fouled

**FMEA ID:** `FM-RVR-001`
**Severity:** Hazardous (loss of last-resort manual control)
**Pre-mitigation likelihood:** ~10⁻³ per flight (uncharacterized cable routing)
**Post-mitigation likelihood:** < 10⁻⁵ per flight

## What it means

The mechanical-reversion path (per [`docs/04`](../../docs/04-fcs-architecture.md))
is the last-line manual control mode for MANTA. When both FCS-A and
FCS-B are unrecoverable, the pilot can engage a direct mechanical
linkage from a stick input to a single set of flaperon surfaces.

Reversion-fault means that path is unavailable when needed:

| Sub-case | Cause |
|---|---|
| Cable run chafed through and broken | Long-cycle operation rubbing against deployed wing structure |
| Reversion cable fouled in deployed wing | Cable gets tangled with rib, spar, or skin on deployment |
| Reversion clutch fails to engage | Mechanical mechanism stuck or jammed |
| Cable end-fitting failure | Swage joint pull-out or fatigue crack |
| Reversion-mode entry inhibited by software | FCS health monitor incorrectly believes a unit is healthy |

In any of those cases, the FCS-failure scenario that prompted reversion
becomes catastrophic: pilot has no envelope protection AND no manual
control. Procedure becomes immediate jettison + reserve.

## Detection

- **Pre-flight functional check** of the reversion path: pilot or
  ground crew engages reversion mode (with FCS power off) and verifies
  the surfaces respond to stick input across the full deflection range.
  Refuses to fly if any surface fails to track.
- **Cable tension sensors** (one per cable): report cable tension, slack,
  and over-tension. Loss of tension indicates a broken cable or end
  fitting.
- **Clutch-engaged microswitch**: confirms mechanical clutch is in the
  reversion-engaged position when commanded.
- **In-flight pilot perception**: stick force feedback. Spongy or
  asymmetric resistance indicates a routing or cable issue.

## Mitigation chain

1. **Routing analysis in CAD.** [`cad/fcs/`](../../cad/fcs/) (TBD content)
   documents the cable routing through the wing root, spar bay, and to
   the flaperon hinges. No path that crosses a deployed structure
   element (no cable lying in the path of an unfurling rib, no cable
   crossing a telescoping joint, etc.).
2. **Cable redundancy.** Two parallel cables to each flaperon surface,
   independently swaged. Single-cable break does not lose the surface.
3. **Cable end-fitting inspection.** Pre-flight visual + tactile check
   of each swage; any cracked / pulled fitting → no fly. Cable life
   limit specified per cycle count, retired well before fatigue
   failure.
4. **Clutch design with positive engagement.** Mechanical clutch fully
   engages with a 50 N pilot stick force; clutch position is sensed
   and reported; cannot enter reversion mode if clutch reports failed
   engagement.
5. **Software interlock.** FCS will engage reversion if EITHER FCS unit
   is faulted AND the other reports degraded EKF. Over-conservative
   triggering is acceptable; under-conservative is not.
6. **Pilot training.** Reversion-mode operation is rehearsed in the
   tow article (`test/tow/`) before manned-deploy flights. Pilot is
   familiar with stick force and surface response in reversion.

## Residual risk

After mitigation:

- **Both parallel cables fail simultaneously** (correlated chafe,
  manufacturing batch defect): ~10⁻⁵ per flight. Mitigated by routing
  separation and per-shipset swage cert.
- **Clutch fault not caught by pre-flight self-test**: ~10⁻⁵ per
  flight. Mitigated by built-in test that exercises the full
  engagement chain.
- **Cable cut during a deployment event** (unlikely but credible —
  e.g. asymmetric deploy that whips a cable): ~10⁻⁶ per deploy.
  Mitigated by routing the cable away from any structure that moves
  during deploy.
- **Pilot can't fly in reversion mode** (Cooper-Harper rating worse
  than expected): not yet measured. If tow-article HQR comes in worse
  than Level 4, reversion becomes a "jettison-only" mode — pilot
  cannot maintain control but the surfaces still move under stick
  input, allowing some attempt at controlled descent before reserve.

## Verification gates

| Gate | What it shows | Where |
|---|---|---|
| Cable routing CAD review | Path clear of all deployed structure motion | `cad/fcs/` |
| Cable cycle test | Single cable survives 10,000 deflection cycles with no failure | Bench |
| Swage strength test | Each end-fitting holds 2× max expected pilot stick load | Bench |
| Reversion-mode pre-flight self-test | Built-in test verifies clutch engagement and surface tracking | Bench HIL |
| Tow-article reversion test | Pilot flies the tow article in reversion mode for at least 5 minutes; Cooper-Harper rated | [`test/tow/`](../../test/tow/) |
| Manned-deploy preconditioning | Pilot has rehearsed reversion-mode entry from cruise + recovery before first manned-deploy flight | Pilot training program |

## Open issues

- Cable routing is not yet detailed. `cad/fcs/build.py` (TBD) needs
  to add the cable runs alongside the FCS hardware placement.
- Reversion-mode pilot input device is unsettled — yoke, stick, or
  body-tilt sensor. Constrained by the deployed-wing pilot ergonomics.
- The tow article is the first place we'll measure handling qualities
  in reversion mode. If HQR is poor, the architecture might need to
  add a low-bandwidth pitch damper that operates even with FCS-A and
  FCS-B faulted (a third independent control authority). That would
  be a substantial design change.

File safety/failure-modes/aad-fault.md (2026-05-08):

# Failure mode: AAD fault

**FMEA ID:** `FM-AAD-001`
**Severity:** Hazardous (loss of last-resort altitude-triggered abort)
**Pre-mitigation likelihood:** ~10⁻⁵ per flight (skydiving baseline; production AAD with current battery)

## What it means

The Automatic Activation Device (AAD) is the FCS-bypassed altitude-and-
descent-rate-triggered abort. On MANTA it has TWO outputs (per
[`docs/05-emergency-systems.md`](../../docs/05-emergency-systems.md)):

1. **Reserve cutter (standard skydiving function)** — fires the
   reserve container's existing cutter if the pilot is below threshold
   altitude AND descending faster than threshold rate.
2. **MANTA wing-cutter trigger** — auxiliary GPIO output that fires
   the wing's pyrotechnic cutters BEFORE the reserve, with a programmed
   100 ms interlock so the wing departs before the reserve canopy
   inflates.

AAD fault means one or both outputs do not fire when they should, OR
fire when they shouldn't.

| Sub-case | Consequence |
|---|---|
| AAD doesn't fire when it should (true emergency) | Pilot impacts terrain at high V — fatal |
| AAD fires when it shouldn't (no emergency) | Surprise reserve deployment in normal flight; pilot must cutaway main and land under reserve |
| Standard reserve cutter fires but MANTA wing trigger doesn't | Reserve deploys with wing still attached — fouling risk |
| MANTA trigger fires but standard reserve doesn't | Wing departs but no reserve — pilot manual reserve required (slow) |

## Detection

- **Pre-flight built-in test** — AAD reports armed status, battery
  voltage, last-pressure-zero, expected firing thresholds. Aircraft
  does NOT fly with a failed AAD self-test.
- **In-flight monitoring** — AAD has an internal supervisor; produces
  a heartbeat on a serial line that the FCS observes. Loss of
  heartbeat → cockpit advisory, but flight continues (AAD is a
  backup, not primary).
- **Post-flight log review** — AAD records altitude/V profile of every
  jump; review confirms it would have fired in any close-call event.

## Mitigation chain

1. **Production-grade AAD with current cert.** Cypres 2 / Vigil 2 / M2
   are fielded skydiving AADs with multi-decade reliability records
   (~10⁻⁶ to 10⁻⁵ per-flight failure-to-fire rate when properly
   maintained).
2. **Independence from FCS.** AAD has its own battery, its own pressure
   sensor, its own logic. FCS-A and FCS-B can both be dead and the AAD
   still functions for the standard reserve fire.
3. **Wing-cutter trigger output isolation.** AAD's GPIO drives the wing
   cutter firing circuit through an independent power rail (separate
   from FCS-A and FCS-B rails), so a power-system fault that takes both
   FCS units does not also take the AAD trigger path.
4. **Two-path firing of the wing cutters** — even if AAD's trigger
   output fails, FCS-A and FCS-B both have independent fire-cutter
   paths. AAD path is the *third* independent route, used when the
   FCS units are themselves unable to issue the command.
5. **Programmed wing-then-reserve interlock.** AAD fires its standard
   reserve cutter 100 ms AFTER the wing-cutter trigger. If the wing
   cutter trigger somehow fails but the reserve cutter still fires,
   the reserve canopy inflates with the wing still attached — the
   reserve-compatibility analysis ([`safety/reserve-compat.md`](../reserve-compat.md))
   has a residual-risk entry for this.
6. **Pre-flight inspection requirement.** Rigger or pilot verifies AAD
   is armed, battery date current, last-pressure-zero done within 24 h
   (or per AAD manufacturer spec). Failed inspection = no fly.

## Residual risk

After mitigation:

- **AAD complete failure to fire**: ~10⁻⁵ per flight (skydiving
  baseline; FCS-driven abort paths catch most credible MANTA
  emergencies, so AAD's role is genuinely "last resort"). For MANTA
  specifically, the FCS ABORT paths (`docs/03`) cover ~99 % of
  credible failure modes; AAD adds another order of magnitude of
  defense for the remaining ~1 %.
- **AAD inadvertent fire**: ~10⁻⁶ per flight. Same as standard
  skydiving — the failure mode is not specific to MANTA. Recovery is
  a normal cutaway-and-reserve descent.
- **AAD fires standard reserve but not MANTA wing trigger**: ~10⁻⁶
  per flight. This is the binding case for the reserve-compatibility
  analysis — reserve canopy attempting to inflate with wing still
  attached. Residual catastrophic risk requires that the wing
  jettison stub geometry be clear of the reserve cone (verified in
  `cad/harness/build.py` clearance check).

## Verification gates

| Gate | What it shows | Where |
|---|---|---|
| AAD vendor cert | AAD passes manufacturer reliability and field-failure data | Vendor documentation |
| AAD-to-cutter wiring loop test | GPIO output drives the wing cutter firing circuit at the required current | Bench |
| AAD power-rail independence | AAD-bypass path operates with FCS-A and FCS-B both unpowered | Bench |
| AAD pre-flight self-test | Armed-status, battery, pressure-zero readouts agree with manufacturer expectations | Pre-flight checklist |
| AAD timing interlock | 100 ms delay between wing-cutter trigger and standard reserve cutter is correctly programmed and verified | Bench |
| Drop article AAD-trigger scenario | Forced AAD trigger fires wing cutters, then reserve, in the right order | [`test/drop/`](../../test/drop/) |

## Open issues

- AAD vendor selection. Down-select from Cypres / Vigil / M2 based on
  GPIO output capability (the auxiliary output for the wing cutter
  trigger), serial heartbeat support, and operating-temperature
  envelope match to MANTA's −10 °C floor.
- Custom firmware load on the AAD if the vendor doesn't ship the
  required interlock timing — most production AADs allow some
  programmability but the interface is vendor-proprietary.
- AAD altitude-threshold setting. Standard skydiving AADs fire at
  ~225 m AGL. With MANTA's 100 ms wing-then-reserve interlock plus
  drogue / wing-clear time, the practical altitude floor for safe
  AAD operation is ~325 m AGL. Recommend setting AAD threshold to
  match this.

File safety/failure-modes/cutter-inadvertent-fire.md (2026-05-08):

# Failure mode: pyrotechnic cutter inadvertent fire

**FMEA ID:** `FM-CUT-002`
**Severity:** Catastrophic if airborne; major if on the ground
**Pre-mitigation likelihood:** ~10⁻⁴ per cutter operating hour (no lockout, ungated arm)
**Post-mitigation likelihood:** < 10⁻⁷ per cutter operating hour

## What it means

A pyrotechnic cutter fires when it should not. Possible triggers
(in roughly increasing order of difficulty to defend against):

| Trigger | Mechanism |
|---|---|
| Static discharge into initiator | Body or atmospheric ESD couples into firing leads |
| EMI / lightning | Radio-frequency or lightning-induced current in firing leads |
| Software bug | FCS issues a fire command in a state where it shouldn't |
| Hardware fault | Latch-up, stuck-on transistor, shorted firing capacitor |
| Mishandling | Lockout pin removed too early; arm switch closed at wrong time |
| Ground-handling event | Drop, impact, vehicle crash with wing on top |

Consequence depends on flight phase:

- **On the ground**: cutter fires on a still-bonded fitting; aluminum
  fitting deformed, possible hand injury, definite shipset write-off.
  Major property damage but no fatality if procedures followed.
- **In flight, pre-deploy** (wing stowed): one cutter firing on a
  stowed wing severs that root early; if the wing then deploys the
  asymmetric-deploy detector fires the other 3 cutters, jettison + reserve.
  Catastrophic only if the firing event happens at altitude where
  reserve event is not survivable.
- **In flight, post-deploy** (wing flying): one cutter firing severs
  one spar at the root; immediate roll departure; FCS detects roll
  rate divergence and fires the other 3 cutters → jettison + reserve.
  Catastrophic if cutters fail or pilot below reserve altitude.

## Detection

Pre-fire (the only useful detection — once it's fired, the cutter is
done):

- **Initiator continuity monitoring** — FCS checks the firing-circuit
  loop continuity at 10 Hz. A short or unexplained current flow flags
  inadvertent-fire risk; the system commands jettison-inhibit and pilot
  manual abort.
- **Lockout state monitoring** — the mechanical lockout pin has a
  microswitch that reports "engaged" or "removed". Should be engaged
  in any pre-flight state and removed only as part of the deliberate
  arm sequence.

## Mitigation chain

The architecture has **three independent layers** that must all be
defeated for an inadvertent fire to occur:

1. **Mechanical lockout pin.** A physical pin blocks the LSC from
   propagating into the spar even if the initiator fires. The pin is
   removed manually as the *first* step of the arm sequence (pilot or
   rigger physically pulls a lanyard). The lockout pin engaged
   condition is monitored by a microswitch.

2. **Electrical arm relay.** The firing-circuit power is routed
   through a relay that is OPEN by default. The relay closes only
   when the FCS state machine transitions out of the pre-deploy
   states (i.e. the system is committed to deployment). Loss of FCS
   power = relay opens = no firing power.

3. **Two-stage fire command.** The actual fire command requires TWO
   simultaneous signals on independent buses: a timing pulse from
   FCS-A and a permission gate from FCS-B (or vice versa). A single-
   FCS software bug cannot fire the cutter alone.

In addition:

4. **EMI hardening per RTCA DO-160 G H.** Firing-circuit shielding,
   filtered penetrations, twisted-pair leads with shield drain.
   Tested to 200 V/m HIRF per Category L (severe environment).

5. **No-fire / all-fire margins.** B-basis-tested LSC + initiator
   such that the no-fire current (1 W / 1 A for 5 minutes) is well
   below any conceivable EMI-induced current at the initiator pad.

6. **Ground-handling protocols.** No live initiators installed in the
   cutters until the aircraft is on the dispatch line. Initiators
   ship in static-shielded packaging and are installed by a qualified
   rigger as part of the pre-flight sequence.

7. **Pre-flight built-in test** of the firing-circuit continuity and
   the lockout / arm chain before initiators are installed.

## Residual risk

After all layers:

- **Common-mode hardware fault** (latch-up that closes both the arm
  relay AND the dual-fire-command gates simultaneously): ~10⁻⁸ per
  flight. Mitigated by independent relay technology (one
  electromechanical, one solid-state) so the same fault doesn't take
  both.
- **Software bug that fires both gates at the wrong state**:
  ~10⁻⁷ per flight. Mitigated by code review, scenario-based testing,
  and the fact that FCS-A and FCS-B run independently-developed
  logic at the gate level.
- **Lightning strike or extreme HIRF event**: not credible at
  skydiving altitudes; for high-altitude deployment scenarios
  outside MANTA v1, a separate lightning analysis is required.
- **Mishandling**: residual is procedural-discipline, not hardware.
  Pre-flight checklist + dual rigger sign-off is the mitigation;
  residual ~10⁻⁵ per flight assumes properly trained operators.

## Verification gates

| Gate | What it shows | Where |
|---|---|---|
| LSC + initiator no-fire/all-fire B-basis | Firing thresholds well-separated from EMI environment | Vendor lab |
| EMI immunity test (DO-160 G H) | No fire under 200 V/m HIRF, lightning-induced transients, ESD | EMI test lab |
| Lockout cycle test (×100) | Pin engages/disengages reliably; microswitch reports correctly | Bench |
| Arm-relay independence test | Relay opens when FCS-A or FCS-B is unpowered; remains open when both unpowered | Bench |
| Two-stage fire-command logic | Single-source fire command does NOT fire the cutter | Bench HIL |
| Software regression suite | Scenario tests prove no software-side path issues fire on pre-deploy states | CI / SITL |
| Ground-handling drop test | Cutter assembly survives 1.5 m drop onto concrete with no inadvertent fire | Bench |
| Operations sign-off | Pre-flight checklist signed by rigger AND pilot before initiators installed | Operational doc |

## Open issues

- Initiator vendor selection. Need NSI or equivalent with documented
  ESD insensitivity (5 kV / 500 pF) and a clear no-fire margin.
- Lockout pin geometry — must NOT be defeatable by vibration alone but
  must be removable by hand without tools.
- Two-stage fire-command implementation: the timing window between
  FCS-A pulse and FCS-B gate is a tradeoff between false-firing
  protection (longer = better protection, more chance of mismatch)
  and intentional-fire latency. Default 5 ms; tune from bench data.
- Static ground prior to initiator install — every aircraft needs a
  documented static-ground point and a wrist strap protocol for
  riggers handling initiators.

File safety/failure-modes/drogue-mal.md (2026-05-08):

# Failure mode: drogue malfunction

**FMEA ID:** `FM-DEP-002`
**Severity:** Catastrophic
**Pre-mitigation likelihood:** ~10⁻³ per deployment (single drogue, no bypass logic)
**Post-mitigation likelihood:** < 10⁻⁵ per deployment

## What it means

The drogue chute fails to inflate, fails to inflate symmetrically, or
fails to release after wing deploy. Each sub-case has different
consequences:

| Sub-case | Consequence |
|---|---|
| Pilot chute (PC) misfire — drogue never extracts | Pilot stays at terminal; no deceleration; wing deploy at high q is structurally unsafe |
| Drogue inverts during inflation | Greatly reduced drag; deceleration to wing-deploy V takes much longer or never reaches it |
| Bridle line snag on the harness | Drogue inflates but doesn't load the bridle; same effect as no drogue |
| Drogue release after wing-stable fails | Drogue continues to load aft; affects wing trim acquisition; may damage wing or pull pilot off-trim |

## Time budget

From [`analysis/deployment/drogue_dynamics.py`](../../analysis/deployment/drogue_dynamics.py)
the nominal drogue inflates in ~0.45 s and decelerates the system from
55 m/s to 30 m/s in ~4.7 s. The deployment state machine
([`analysis/deployment/state_machine.py`](../../analysis/deployment/state_machine.py))
gives the drogue 4.0 s to reach 50 % nominal load before declaring a
malfunction. That timeout is conservatively the ~time required to
clear the drogue extract and inflation transient with margin.

## Detection

| Channel | What it shows |
|---|---|
| Drogue load cell on the bridle | Direct measurement; nominal trace is a fast rise to ≥ 50 % within 1.5 s of extract |
| Pitot-static airspeed | Nominal V drops from 55 → ~30 m/s in 4.7 s; flat trace = drogue not effective |
| Body axis accel | Drogue inflation produces ~0.5 g forward decel pulse; absence indicates problem |
| IMU body rates | Drogue stable should keep body rates low; spinning indicates inversion or asymmetric inflation |

The state-machine gate uses **drogue load AND airspeed-below-32 m/s**.
Either signal failing within 4.0 s triggers the abort path.

## Response

```
drogue mal detected at 4.0 s post extract
       │
       ├──► (preferred)  bypass drogue, command immediate jettison
       │                 → wing has not deployed → "jettison" of stowed wing
       │                   means firing the cutters on a still-stowed wing
       │                   to release wing assembly to fall clear
       │                 → pilot manual reserve (no AAD trigger yet at altitude)
       │
       └──► (fallback)   pilot manual reserve (cutaway main path)
                         only used if FCS jettison-fire path is faulted
```

The "jettison stowed wing" sub-case is unusual in skydiving — pre-deploy
abort that includes pyrotechnic separation of an undeployed wing. The
wing assembly is still close to the body in the stowed configuration;
firing cutters at that point releases the assembly to fall away. The
geometry is exercised once on the drop article ([`test/drop/`](../../test/drop/)).

## Mitigation chain

1. **Drogue bag + PC pre-flight check** — visual inspection that the
   PC is properly cocked, the bag is closed, the bridle is routed
   through the tunnel without snags. Standard skydiving rigger
   protocol; rigger-signoff required pre-flight.
2. **Drogue PC firing redundancy** — both spring-loaded PC and a
   timed mechanical extraction backup if PC doesn't pull the bag at 1 s.
3. **Drogue load cell as gate** — explicit detection threshold in the
   state machine, not relying on attitude or pilot perception.
4. **Drogue bypass logic** — state machine fires jettison + reserve
   on drogue mal rather than continuing into wing deploy at terminal q.
5. **Drogue release mechanism** redundancy — two independent paths to
   sever the drogue bridle after wing-stable; failure to release on the
   primary path triggers the secondary on a 0.5 s timeout.

## Residual risk

After mitigation:

- **Drogue PC and timed backup BOTH fail** (~10⁻⁶ per flight, mitigated by
  pre-flight inspection and field-tested PC hardware): residual ~10⁻⁶.
- **Drogue load cell signals "good" but is faulty** (sensor failure):
  cross-checked against airspeed. Both signals failing simultaneously
  requires correlated faults that should not happen with independent
  channels. Residual ~10⁻⁷.
- **Drogue release fails on both paths**: the trailing drogue at deployed
  wing condition affects trim. Pilot can manually cut bridle if pilot has
  reach (depends on `cad/harness/`). Residual major (loss of glide
  performance), not catastrophic.

## Verification gates

| Gate | What it shows | Where |
|---|---|---|
| Drogue inflation profile bench | Inflation time, peak load, dispersion | Bench drogue test |
| Drogue load cell calibration | Load cell reads bridle tension accurately at the rates of interest | Bench |
| Drogue PC firing reliability | PC fires within 1 s in 50+ trials | Bench / drop article |
| Drop article — drogue mal sub-cases | Each sub-case (PC misfire, inversion, late inflation, release fail) exercised on instrumented test article | [`test/drop/`](../../test/drop/) |
| State-machine bypass logic | Software fires jettison + reserve within budget on drogue-mal trigger | SITL + drop |
| Drogue release redundancy | Both paths exercised independently | Bench + drop |

## Open issues

- Drogue stability at terminal V — ringslot drogues have characteristic
  body-axis stability but can squidge at certain V/q combinations.
  Bench dynamic stability characterization needed.
- Bridle attachment-point load distribution on the harness — same
  3.94 kN snatch peak (per `analysis/deployment/drogue_dynamics.py`)
  needs to be in the harness mount load case.
- Drogue release: pyrotechnic vs. mechanical line-cutter is not
  selected. Pyrotechnic is faster and more reliable but adds another
  initiator to the system.

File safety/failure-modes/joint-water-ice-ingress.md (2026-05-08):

# Failure mode: telescoping joint water/ice ingress

**FMEA ID:** `FM-JNT-001`
**Severity:** Major (fails to deploy on one or more stages — drives jettison)
**Pre-mitigation likelihood:** Unknown — ground-rig characterization gate
**Post-mitigation likelihood (target):** < 10⁻³ per flight in operational envelope

## What it means

The telescoping CFRP spar joints have small clearances (2–5 mm radial
between adjacent stages) for the inner stage to slide free of the outer.
Water that enters the joint can:

- Increase friction (water film between sliding surfaces)
- Freeze in cold conditions, locking the joint
- Corrode the locking-pin hardware (less of an issue with CFRP +
  stainless pins, but if any aluminum is present in the joint stack,
  galvanic corrosion accelerates)

In any of those conditions a stage may fail to extend, fail to lock,
or extend slowly. Per [`analysis/deployment/symmetry-budget.md`](../../analysis/deployment/symmetry-budget.md)
the spar-friction term is 2 ms 3-σ contribution to the symmetry
budget — second-largest contributor after CO2 cartridge variance, and
the contribution **doubles or triples in cold/wet conditions** per
field experience with telescoping CF spar systems.

## Effect

Spar-friction induced asymmetry feeds directly into the symmetry budget:

| Ambient state | Spar-friction σ_t (modeled) | Combined 3-σ |Δt| (modeled, all contributors) |
|---|---|---|
| Nominal (+20 °C, 50 % RH) | 2.0 ms | 16.3 ms |
| Cold dry (−10 °C) | 3.0 ms | ~19 ms |
| Cold wet (−5 °C, soaked) | 4.5 ms | ~24 ms |
| Cold iced (−5 °C, frozen ingress) | unknown — could be infinite (binding) | unknown |

The cold-iced case is what the BRIEF specifically calls out as
unsolved-problem #4. If a stage doesn't extend at all, the per-side
deploy time on one side becomes much greater than on the other — the
asymmetric-deploy detector fires jettison ([`safety/failure-modes/asymmetric-deployment.md`](asymmetric-deployment.md)).
**No-deploy on one side is recoverable via jettison + reserve**, but the
flight is over.

## Detection

- **Per-stage spar-lock microswitch** — direct evidence that the stage
  did or didn't reach its locked position. Failure to latch within 50 ms
  of deploy command on one or more locks → state machine treats as
  asymmetric deploy / lock-fail abort.
- **Pre-flight environmental conditioning check** — pilot or rigger
  verifies the spar joints are clean and dry before stowing the wing.
  This is a procedural mitigation; effectiveness depends on operator
  discipline.

## Mitigation chain

1. **Sealed joints.** Each telescoping stage joint has lip seals
   (silicone or fluorocarbon) at the outer-tube end that scrape water
   and debris from the inner tube as it extends. Same approach as
   high-end fishing rods and surveying tripods — well-characterized
   technology.
2. **Drainage paths.** Small drilled holes near the joint allow any
   water that does get past the lip seal to drain out as the spar
   extends. Holes are positioned so they're internal in the stowed
   configuration (so they don't whistle or admit water in flight).
3. **Hydrophobic coatings** on the sliding surfaces (PTFE-based dry
   lubricant, applied during build and refreshed periodically).
4. **Ground-rig environmental conditioning gate.** Per
   [`test/ground/spec.md`](../../test/ground/spec.md):
   25 cycles in cold/wet, 25 in cold/iced, with 50 % failure rate
   in either category aborting the gate run. The rig is the
   measurement that converts this from "unknown" to a quantified
   distribution.
5. **Pre-flight check** — visual inspection of the lip seals (tear or
   lift = no fly), drainage holes (clogged = no fly), and spar
   surface condition (visible water film = wipe dry; visible ice =
   no fly until thawed).
6. **Dispatch envelope.** No flight at ambient T < −10 °C until the
   ground rig demonstrates the 200-cycle gate at the next-colder
   temperature with no failures. The operational envelope GROWS with
   demonstrated reliability.
7. **Asymmetric-deploy detection** as the safety net — even if one
   stage fails to extend, the asymmetric detector fires jettison
   within 75 ms of detection.

## Residual risk

After mitigation:

- **Sealed-joint failure (seal tear or lift) admitting water** that the
  pre-flight check misses: ~10⁻³ per flight, residual major (asymmetric
  deploy → jettison). Catastrophic only if the cutters also fail
  (`FM-CUT-001`), which combines to < 10⁻⁸ per flight.
- **Cold-soak deeper than the operational envelope**: pilot procedural
  mitigation only. Residual is dispatching outside the envelope, which
  is a discipline problem, not a hardware problem.
- **Microswitch fault at the same time as joint binding** (so the
  state machine doesn't see the no-lock signal): mitigated by the
  dual-contact microswitch design (per [`docs/03`](../../docs/03-deployment-sequence.md)).
  Residual <10⁻⁵ per flight.

## Verification gates

| Gate | What it shows | Where |
|---|---|---|
| Lip-seal coupon test | Seal integrity over the operating-temperature range and 1000 sliding cycles | Bench |
| Drainage geometry test | Water introduced at joint drains under representative deploy kinematics | Bench |
| Cold-soak deploy test (uninstalled spar) | Joint friction measured at −10 °C, dry vs. wet vs. iced | Bench |
| Ground-rig cold/wet runs (×25) | Full wing assembly deploys symmetrically with cold-soaked + spray-soaked spars | [`test/ground/spec.md`](../../test/ground/spec.md) |
| Ground-rig cold/iced runs (×25) | Same with frozen ingress — the binding case | Same |
| Pre-flight checklist | Documented and rehearsed; rigger sign-off required | Operational doc TBD |

## Open issues

- Lip-seal vendor selection. Off-the-shelf options (Trelleborg, SKF,
  custom fluorocarbon) need to be matched to the operating-temperature
  range and sliding-cycle life.
- Drainage hole geometry — must drain water but not admit it during
  flight. The flow direction reverses between stowed and deployed
  configurations.
- Galvanic-corrosion analysis if any non-CFRP hardware (locking pins,
  spring-energizers) is used in the joint stack. Stainless-on-CFRP is
  acceptable; aluminum-on-CFRP is not.
- The cold-iced characterization on the ground rig is a binding gate.
  If the rig cannot achieve 200 cycles in the cold-iced category, the
  operational envelope contracts (no flight in conditions where
  ingress can freeze) — a substantial mission limitation for
  cold-weather skydiving operations.

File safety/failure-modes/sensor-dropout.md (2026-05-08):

# Failure mode: sensor dropout

**FMEA ID:** `FM-SEN-001` (umbrella; per-channel sub-IDs in parentheses below)
**Severity:** Varies by channel — see table
**Pre-mitigation likelihood:** ~10⁻³ per channel per flight (no redundancy)
**Post-mitigation likelihood:** < 10⁻⁵ per flight (overall vehicle outcome)

## What it means

Any sensor channel reports invalid data — either silent (no signal),
stuck (frozen value), out-of-range, or noisy beyond filter rejection.
The FCS detects via cross-check and either downgrades to a backup
channel or enters degraded-mode operation.

## Per-channel response matrix

| Sub-ID | Channel | Severity | Detection | Mitigation | Residual |
|---|---|---|---|---|---|
| `FM-SEN-IMU-001` | One IMU (of 3) | Minor | EKF residual + cross-check between FCS-A IMU, FCS-B IMU, aux IMU | Voting drops the bad IMU; 2-of-3 still active | < 10⁻⁵ per flight |
| `FM-SEN-IMU-002` | Two IMUs simultaneously | Hazardous | Same — two channels disagree with the third | Single remaining IMU is authoritative; Cooper-Harper degrades but flyable; recommend reserve at next safe altitude | < 10⁻⁷ per flight (correlated 2-of-3 failure) |
| `FM-SEN-IMU-003` | All three IMUs | Catastrophic | EKF cannot resolve; FCS faults | Mechanical reversion (no envelope protection); pilot procedure: jettison + reserve | < 10⁻⁸ per flight |
| `FM-SEN-PIT-001` | One pitot-static | Minor | Cross-check vs. the other pitot AND vs. GNSS ground speed | Use the healthy channel; mild EKF re-tune | < 10⁻⁴ per flight |
| `FM-SEN-PIT-002` | Both pitot-static | Hazardous (especially in gusty conditions) | Both channels disagree with GNSS-derived ground speed by > threshold | Use GNSS ground speed as airspeed proxy (degraded — wind error); widen alpha-limit margin further; cockpit advisory | < 10⁻⁵ per flight |
| `FM-SEN-AOA-001` | AoA vane | Major (degraded alpha-limiter authority) | Vane signal validity flag; cross-check against EKF body-rate-derived alpha estimate | Degraded-mode alpha estimate from trim equation; alpha-limit margin widened by 1.5° (per `fcs/envelope_protection/alpha_limiter.py`) | < 10⁻³ per flight |
| `FM-SEN-LCK-001` | One spar-lock microswitch | Catastrophic *only* during deploy gate evaluation | Within-budget time-out on the affected channel; redundant dual contacts on the same switch help | Lock-fail-timeout fires jettison + reserve; pilot proceeds under canopy | < 10⁻⁵ per deploy |
| `FM-SEN-LCK-002` | Multiple spar-lock channels | Catastrophic if the failure happens during the deploy gate window | Same — but multiple-channel timeouts are more decisive | Same response; jettison + reserve is fail-safe | < 10⁻⁶ per deploy |
| `FM-SEN-DRG-001` | Drogue load cell | Catastrophic if false-positive | Cross-check vs. accel signature and airspeed trace | If load cell silent, fall back to airspeed gate; if airspeed also fails, time-based bypass after 4 s | < 10⁻⁴ per deploy |
| `FM-SEN-MAG-001` | Magnetometer | Minor | EKF heading divergence vs. GNSS course | EKF runs without magnetometer using GNSS-derived course; brief degraded heading; not flight-critical | < 10⁻³ per flight |
| `FM-SEN-GNSS-001` | GNSS | Major (loss of altitude-rate / horizontal-position cross-check) | EKF residual + standard GNSS health flags | EKF runs without GNSS at the cost of slow position drift; fine for the duration of a glide; informs reserve-altitude alarm | < 10⁻³ per flight |

## Cross-channel correlations

Some sensor failures are **correlated** — a single fault can take
multiple channels down at once. The mitigation strategy assumes
INDEPENDENT failures; correlated failures bypass the redundancy.

| Correlated event | Channels affected | Mitigation |
|---|---|---|
| Common power-rail failure | All sensors on that rail | FCS-A, FCS-B, AAD on independent rails; rail-monitoring on each |
| EMI / lightning event | Many digital channels simultaneously | DO-160 hardening; transient suppression on every penetrating wire |
| Airframe vibration mode at sensor mounting frequency | All vibration-coupled MEMS sensors | Vibration isolation on the IMU mounts; calibration sweep across operational frequency range |
| Thermal-shock stripe | Sensors in a single thermal environment | Spatial separation of the redundant channels (FCS-A in fwd bay, FCS-B in aft bay); independent thermal management |
| Ground-strike or hard landing | Mechanically-coupled sensors | Each sensor mount sized to its channel's load case; G-load survival testing per DO-160 Cat S |

## Detection latency

The state machine and inner-loop control are time-sensitive. The EKF
runs at 400 Hz; sensor-fault flags must propagate within ≤ 10 ms of the
fault-condition becoming detectable, and the inner loop must respond
within ≤ 25 ms (10 control cycles) of the flag setting.

Fault-detection latency is a verifiable property of the FCS firmware;
target test in HIL fixture is 95 % of detected faults flag within 10 ms.

## Mitigation chain (overall)

1. **Triplex redundancy** on the most safety-critical channel (IMU).
2. **Duplex redundancy** on next-most-critical (FCS, pitot, spar-lock
   contacts on a single switch).
3. **Single-channel + degraded-mode fallback** on AoA vane, drogue
   load cell, magnetometer, GNSS.
4. **Cross-channel cross-checking** so a frozen / stuck value is
   detected as easily as a silent one.
5. **Heartbeat monitoring** on every digital sensor: missing heartbeat
   = invalid.
6. **Per-channel pre-flight self-test** that the sensor reports the
   expected value at the expected condition (e.g. AoA vane reads
   within ±1° of zero with the aircraft level on the ground).
7. **Cockpit advisories** on any sensor degraded-mode entry; pilot
   informed of which channel and what the consequence is for envelope
   protection authority.

## Residual risk

After mitigation:

- **Single-channel failures** are essentially eliminated by redundancy
  for the IMU and pitot, and well-handled by graceful degradation
  for AoA / mag / GNSS.
- **Correlated multi-channel failures** are the residual risk. Most
  credible: a vibration mode that hits all IMUs (mitigated by
  isolation testing); a power-rail fault (mitigated by independent
  rails); EMI / lightning (mitigated by DO-160 hardening — but
  unverified at MANTA-program scale).
- **Unknown sensor-fault modes** that the per-channel detection
  doesn't catch: hard to quantify. Mitigated by EKF residual
  monitoring (any sensor whose output is inconsistent with the rest
  of the state estimate gets flagged), but residual ~10⁻⁵ per flight.

## Verification gates

| Gate | What it shows | Where |
|---|---|---|
| Per-channel injection test | Each sensor channel forced into invalid / stuck / out-of-range states; FCS detects within latency budget | Bench HIL |
| Cross-channel disagreement test | Two sensors of the same kind disagree; voting works as designed | Bench HIL |
| Power-rail independence | Each rail can be cycled independently with no loss of redundancy on others | Bench |
| Vibration sweep | IMUs do not couple to airframe vibration modes through their mounts | Bench shaker test |
| EMI immunity | Sensor channels survive DO-160 G H HIRF + lightning transient | EMI test lab |
| End-to-end SITL with sensor faults | Full deployment scenario with each sensor injected as failed; state machine + control responds correctly | PX4 SITL |

## Open issues

- Sensor selection is still placeholder. Each per-channel reliability
  number above assumes "production-grade aerospace MEMS / load cell"
  sourcing. Vendor-specific reliability data would tighten the
  estimates.
- Vibration-isolation analysis is not yet done. Until the airframe is
  built and a representative mass model is shaken, the IMU-to-airframe
  resonance assumption is uncharacterized.
- HIRF / lightning testing for a non-cert program is expensive and
  rarely done. Compromise approach: vendor-cert components where
  possible; bench-level transient injection on the firing circuit only.

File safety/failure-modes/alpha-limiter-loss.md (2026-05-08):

# Failure mode: alpha-limiter loss

**FMEA ID:** `FM-FCS-001`
**Severity:** Hazardous
**Pre-mitigation likelihood:** ~10⁻³ per flight (single-FCS, AoA-vane-only)
**Post-mitigation likelihood:** < 10⁻⁵ per flight (redundant FCS + degraded-mode α estimate)

## Why this matters more for MANTA than for a conventional aircraft

Per `BRIEF.md`:

> Stall departure on a tailless high-AR wing is unforgiving. Alpha limiter
> in the FCS is mandatory; not a feature, a structural design assumption.

The structural sizing in `analysis/struct/spar_bending.py` assumes the
alpha limiter is functional — the wing is sized to 3 g limit / 4.5 g
ultimate, on the assumption that the FCS prevents the wing from being
operated at α > α_limit even under gust + pilot-CG-perturbation
disturbances. **Loss of the limiter does NOT immediately lose the
vehicle**, but it removes the protection that prevents the wing from
being kicked into an unsizable load case.

The pilot-CG-perturbation analysis in
[`analysis/flightdynamics/longitudinal.py`](../../analysis/flightdynamics/longitudinal.py)
makes this concrete: a 50 mm aft head/torso shift produces a 3.26 % MAC
vehicle CG shift, comparable to the entire 5.4 % MAC static margin.
Without active envelope protection, a worst-case posture transient at
high CL can put the wing into negative static margin and stall departure.

## Causes

| Cause | Effect on limiter | Detection |
|---|---|---|
| AoA vane mechanically stuck or iced | Limiter sees fixed α; clamps when vehicle isn't actually high-α (or vice versa) | EKF cross-check vs. body-rate-derived α; vane heater current monitoring |
| AoA vane disconnected / cabling fault | Limiter falls to degraded-mode α estimate | Vane signal validity flag |
| Pitot-static failure (both channels) | Degraded-mode estimate also unreliable (depends on V) | Pitot health flags + EKF-V-vs-GNSS-V cross-check |
| FCS-A fault | Limiter handed off to FCS-B; ~100 ms transition | FCS health monitor |
| FCS-A AND FCS-B both fault | Limiter unavailable; mechanical reversion has no envelope protection | Health monitor → mechanical-reversion mode |
| Software bug | Limiter logic doesn't engage when it should | Pre-flight built-in test + ground-rig validation |

## Detection chain

The limiter has *three* layers of monitoring, in order of immediacy:

1. **AoA vane validity flag** (per FCS, EKF output): set false when the
   vane is mechanically stuck, frozen, or signaling outside its
   physical range. Triggers degraded-mode α estimate.
2. **FCS health monitor**: cross-checks limiter outputs between FCS-A
   and FCS-B. Disagreement on `alpha_cmd_deg` by more than 1° at the
   same input → fault flag → swap to healthy unit (or both if both
   show fault).
3. **Body-rate plausibility**: if the EKF observes pitch rate q
   inconsistent with the commanded α (e.g. limiter says "saturated at 9°"
   but the vehicle is pitching up rapidly, suggesting α is rising past
   the limit), the FCS flags limiter-ineffective.

## Response

### Limiter degraded but still functional

- Layer 1 trip (AoA vane fault): switch to degraded-mode α estimate
  (trim equation: α = α₀ + (1/CL_α)·(m·g)/(½·ρ·V²·S)). Widen the limit
  margin by 1.5° (per [`fcs/envelope_protection/alpha_limiter.py`](../../fcs/envelope_protection/alpha_limiter.py)).
  Inform pilot via cockpit alert.

- Layer 2 trip (FCS-A vs FCS-B disagreement): swap to the healthy unit;
  pilot informed; flight may continue at reduced authority near stall
  if the degraded-mode estimate is also active.

### Limiter fully unavailable

- Layer 3 trip OR both FCS units faulted simultaneously:
  - Engage **mechanical reversion**. Pilot has direct cable to the
    flaperons; *no* envelope protection.
  - Pilot procedure: **Jettison + reserve** at any altitude > 200 m AGL
    where jettison is still safe, OR continue the glide if stable trim
    can be maintained manually and altitude / terrain permit a landing
    under canopy without recurring instability.
  - Do NOT attempt aerobatic maneuvers, slow flight, or aggressive
    maneuvering in this mode.

The procedure favors jettison + reserve because:
- The wing's natural instability with full pilot CG perturbations
  exceeds typical pilot bandwidth at high CL.
- A flapping reserve canopy is a far more forgiving descent vehicle
  than a tailless flying wing without envelope protection.

## Mitigation

| Layer | Mitigation |
|---|---|
| Hardware redundancy | Two FCS units (independent power rails, independent IMUs, independent cabling); aux IMU on FCS-B; cross-checked EKFs |
| Sensor redundancy | AoA vane → degraded-mode estimate from trim equation when vane fails. The trim equation only needs V and m·g; widely-redundant inputs |
| Software | Limiter is testable in isolation ([`fcs/envelope_protection/tests/`](../../fcs/envelope_protection/tests/)). 7 unit tests cover saturation, degraded mode, low-V tightening, never-exceeds-stall. Adding scenarios is cheap |
| Pre-flight | Built-in test exercises the limiter saturation path with an injected pilot α command at the limit; observed `saturated` flag must agree on FCS-A and FCS-B |
| Pilot training | Mechanical-reversion procedure rehearsed in tow article (`test/tow/`) before manned-deploy flights |

## Residual risk

After mitigation, the catastrophic-loss-of-limiter scenarios that remain:

- **Common-mode software bug** that affects both FCS units identically.
  Mitigated by code review, scenario-based testing, and PX4/ArduPilot
  software-quality inheritance from the upstream project. Residual
  ~ 10⁻⁵ per flight.
- **Common-mode environmental fault** (lightning strike, mass EMI event)
  that takes both FCS units. Mitigated by DO-160 EMI testing and
  separated power rails. Residual ~ 10⁻⁶ per flight.
- **Mechanical reversion AND structural overload simultaneously** —
  i.e. the limiter loss and a pilot-CG transient both occur in the same
  flight before pilot can jettison. Residual ~ 10⁻⁷ per flight.

## Verification gates

| Gate | What it shows | Where |
|---|---|---|
| Limiter unit tests | Logic is correct in isolation | [`fcs/envelope_protection/tests/`](../../fcs/envelope_protection/tests/) (7 tests passing) |
| Closed-loop scenarios | Limiter saturates correctly under pilot over-command | [`fcs/sim/closed_loop.py`](../../fcs/sim/closed_loop.py) |
| Sensor-fault SITL | Degraded-mode estimate behavior in PX4 SITL across V envelope | TBD — PX4 SITL once it exists |
| Built-in test | Pre-flight verification that limiter saturates as expected | TBD — bench HIL fixture |
| Tow article validation | Limiter saturates when commanded into stall on a real wing | [`test/tow/`](../../test/tow/) |
| Mechanical reversion rehearsal | Pilot procedure for limiter-loss case practiced before manned-deploy | Tow article + manned-tow training |

## Open issues

- The body-rate plausibility check (layer 3 detection) is described
  here but not yet specified at the algorithmic level. Define the
  threshold (e.g. q > X rad/s while limiter reports saturated) once
  6DOF SITL is in place.
- Cooper-Harper rating in mechanical-reversion mode is unmeasured.
  Tow-article test will provide the first data; if HQR is worse than
  Level 4, mechanical reversion becomes a "jettison-only" mode rather
  than a "potentially fly-able" mode.
- Single-event-upset (SEU) hardening of the FCS firmware against
  cosmic-ray bit flips: skydiving-altitude operation doesn't have a
  cosmic-ray issue, but it's worth noting the issue exists for any
  high-altitude deployment scenario the program might extend to.

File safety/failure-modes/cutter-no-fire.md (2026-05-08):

# Failure mode: pyrotechnic cutter no-fire

**FMEA ID:** `FM-CUT-001`
**Severity:** Catastrophic
**Pre-mitigation likelihood:** ~10⁻³ per cutter, per fire command
(single-initiator, untested LSC)
**Post-mitigation likelihood:** < 10⁻⁵ per cutter (B-basis on dual-initiator
qualified hardware)

## What it means

One or more of the four spar-root cutters fails to sever its spar when
commanded to fire. Possible causes:

- Initiator dud (NSI failed to fire)
- LSC defect (charge fails to propagate, partial cut)
- Electrical fault (firing current did not reach initiator)
- Mechanical / lockout fault (lockout pin not removed pre-flight, or
  arm sequencing prevented fire)
- Cold-soak fault (LSC sensitivity outside operating envelope)

Consequence: when jettison is commanded but fewer than 4 cutters fire,
the wing **does not separate cleanly**. Failure modes downstream include:

- **Partial separation**: 2 or 3 cutters fire, the wing tilts about the
  unfired joint(s) and may flap, exposing the reserve canopy path.
- **Asymmetric separation**: front-pair fires, rear-pair doesn't (or
  vice versa). Wing rotates about the still-attached spar root.
- **No separation**: 0 fires. Wing remains attached; pilot must use
  manual reserve through-the-wing if reserve geometry permits, or
  accept loss of vehicle.

## Why this is binding on the safety case

Cutter-no-fire is the failure mode that defeats the rest of the safety
architecture. Every upstream abort path (asymmetric-deploy detect,
drogue-mal, AAD trigger, pilot manual) ends with **fire the cutters**.
If the cutters don't fire, the abort doesn't recover the situation.

This is the *last-line* failure for ~80 % of credible flight emergencies
in MANTA. Reliability requirements are correspondingly high.

## Detection

The cutter system is **not directly self-monitoring** in the sense of
providing a "fired OK" feedback signal during the fire event itself
(LSC firing happens too fast, ~5 ms, and the resulting current/voltage
signature is destructive to the firing path). Detection is *indirect*:

1. **Spar separation sensors** at each cutter: a microswitch or
   continuity loop that opens when the spar physically separates.
   Closes within 30 ms of fire on a successful cut. Absence of the
   signal at 50 ms after fire = no-fire.
2. **Body rate signature**: a successful 4-cutter fire produces an
   abrupt mass change and a brief asymmetric force pulse. Absence of
   this signature in the IMU within 100 ms of fire confirms no-fire.
3. **Cross-check**: both signals must agree. Single-channel
   disagreement → degraded confidence; both saying "fired" → fired;
   both saying "didn't fire" → re-fire attempt then manual reserve.

## Mitigation chain (in order of independence)

1. **Dual independent initiators per cutter.** Two NSI initiators
   wired to two separate firing paths, each capable of sustaining the
   LSC propagation alone. Probability of both failing simultaneously
   ~ 10⁻⁶ per cutter (vendor B-basis).
2. **Redundant firing circuits.** FCS-A and FCS-B each have an
   independent firing-current path to each cutter, plus the AAD
   FCS-bypass path. Three independent fire-command sources per cutter.
3. **Re-fire on no-fire detection.** If the no-fire signature is
   detected within 50 ms of the first fire command, the FCS commands
   a re-fire on the redundant initiator path. (Programmed delay 30 ms
   between fire and re-fire to allow the no-fire detection window.)
4. **B-basis-tested LSC.** No-fire/all-fire margins per shipset, plus
   acceptance test on every cutter.
5. **Cold-soak qualification.** Cutter operating envelope verified at
   −20 °C (lower than the operational envelope of −10 °C in
   `test/ground/spec.md`).
6. **Pilot manual reserve as final fallback.** If 4-cutter fire fails
   even after re-fire, the pilot pulls the reserve handle. Reserve
   canopy may need to deploy through partial wing structure — risk
   accepted, but quantified in `safety/reserve-compat.md`.

## Time budget for the re-fire path

```
   t = 0     fire command issued
   t = 5 ms  cutters fire (or attempt to)
   t = 30 ms spar separation detected on healthy cuts
   t = 50 ms no-fire detection threshold reached on any unfired cutter
   t = 60 ms re-fire command issued via redundant path
   t = 65 ms second-attempt cutters fire
   t = 95 ms separation detected (or final no-fire confirmation)
```

Total time-to-confirm-jettison-success: **< 100 ms**. The reserve
canopy deployment delay (programmed 100 ms after wing-cutter fire on
AAD-trigger path) is sized to cover this window.

## Residual risk after mitigation

- **Both initiators on one cutter fail** (manufacturing defect, common-
  mode like batch contamination): ≤ 10⁻⁶ per cutter, ≤ 4·10⁻⁶ per
  jettison. **Mitigation:** vendor lot-acceptance testing; do not pull
  initiators from a single batch for all 4 cutters on a given vehicle
  (procedurally enforce two-batch initiator sourcing).
- **All four cutters fail simultaneously** (catastrophic common-mode):
  ≤ 10⁻⁸ per jettison. Plausible only with a systematic fault in the
  firing-circuit power rail. **Mitigation:** independent power rails
  (FCS-A, FCS-B, AAD-bypass), all qualified independently.
- **Lockout fails to disengage** post arm: detected by built-in test
  pre-flight. Aircraft does not fly with a failed lockout test.

## Verification gates

| Gate | What it shows | Where |
|---|---|---|
| Vendor coupon test on the LSC and initiator | No-fire/all-fire B-basis margins | Vendor lab |
| Lot acceptance test per shipset | Margins maintained for the specific cutters being flown | Vendor lab + program acceptance file |
| Bench fire of one cutter on a representative spar root | Cut quality (clean severance, no fiber snag) | In-house bench |
| EMI immunity test (DO-160 H) | Cutter does not inadvertent-fire under HIRF / lightning | EMI test lab |
| Lockout cycle test | 100 cycles of lockout engage/disengage with no failures | In-house bench |
| Cold-soak fire test | Cutter fires nominally at −20 °C | Climate chamber |
| Ground-rig integrated fire test | First live cutter fire on a complete wing assembly in the program | [`test/ground/`](../../test/ground/) |
| Drop article asymmetric-deploy | Real-flight no-fire case is exercised on instrumented test article | [`test/drop/`](../../test/drop/) |
| Re-fire path timing test | Re-fire fires within the 60-ms window post no-fire detection | Bench + drop article |

Until **all gates close**, the residual-risk numbers are predictions.

## Open issues

- Lot-acceptance sample size and reject criteria not yet specified.
  Defer to the vendor's standard practice plus program independent
  review.
- Re-fire timing window (60 ms) is engineering placeholder. Real
  number is the time to confirm a no-fire on the spar separation
  sensor — tightens once the sensor is selected.
- Cutter firing in the asymmetric-deploy *while-deploying* case (i.e.
  the spar is in mid-extension when the cutter is asked to fire on
  it). LSC behavior on a moving spar is plausibly different from on
  a static one. Bench characterization required.

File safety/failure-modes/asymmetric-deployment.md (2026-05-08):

# Failure mode: asymmetric wing deployment

**FMEA ID:** `FM-DEP-001`
**Severity:** Catastrophic
**Pre-mitigation likelihood:** ≈ 25 % per deploy (locked architecture)
**Post-mitigation likelihood:** ≤ 0.3 % per deploy (option-B architecture)

The dominant unrecoverable failure mode for MANTA per `BRIEF.md` and the
unsolved-problem #1 the program is built around. This document is the
single-failure-mode write-up that the safety case turns on; everything
else in `safety/` cross-references it.

## What "asymmetric deployment" means

The two wings deploy with a left-right deploy-time delta exceeding the
10 ms 3-σ envelope the BRIEF requires. The aerodynamic and mechanical
consequences are:

1. **One wing locks before the other** → momentary asymmetric lift →
   roll-rate impulse before the second wing finishes locking.
2. **Skin tension applies asymmetrically** → if it persists, wing twist
   diverges from design.
3. **Drogue is still attached during the deploy event** → drogue tries
   to keep the system facing the relative wind, but the asymmetric
   roll-rate fights it.
4. **Pilot-induced response is too slow** → human reaction time ≥ 200 ms
   is an order of magnitude longer than the deploy event, so manual
   recovery is impossible. Either the FCS catches it, or the abort path
   fires.

If un-aborted, asymmetric deploy ends in:
- Fast roll, possibly into a non-recoverable spin
- Skin/spar damage that prevents stable flight
- Loss of vehicle control before pilot can react
- Reserve canopy deploys into a tumbling configuration with high risk
  of fouling

## Why it is the dominant case

- It is **rapid**: the entire deploy completes in ~50 ms. There is no
  pilot in this loop.
- It is **load-amplifying**: the higher the asymmetry, the higher the
  roll torque, the worse the spar root reaction load on the slow side
  (which still has to absorb the snap-deploy impulse from the fast side
  via cross-spar coupling at the root).
- It is **architecture-coupled to the most complex subsystem** — the
  pneumatic deployment plumbing — and the deployment is a one-shot
  operation with no rehearsal between exit and trim.
- It is **the failure case that compromises the reserve**: a wing
  asymmetric in mid-deploy can foul the reserve deployment path if
  not jettisoned cleanly. Reserve compatibility (`safety/reserve-compat.md`)
  depends on jettison happening cleanly even in the asymmetric case.

## Detection

Two independent detection channels, both wired into the deployment state
machine ([`analysis/deployment/state_machine.py`](../../analysis/deployment/state_machine.py)):

1. **Per-side spar-lock timestamps.** Six microswitches (3 stages × 2
   sides) log lock events with ≤ 1 ms latency. The state machine
   computes Δt_LR between left-fully-locked and right-fully-locked.
   Δt > 10 ms (the BRIEF gate) → fire jettison.

2. **Roll-rate divergence.** During the deploy window (a fixed time box
   of 200 ms after the wing-deploy command), if body roll rate exceeds
   1.5 rad/s, the system fires jettison without waiting for the lock-
   timestamp evaluation. This catches the case where one side locks but
   the other doesn't lock at all (no second timestamp to compare).

Either trigger → jettison + reserve.

## Time budget

| Event | Time after deploy cmd |
|---|---|
| First side begins to deploy | 0 ms (cmd issued) |
| First-side stage 1 lock | ≤ 30 ms |
| First-side stage 3 lock (first side fully open) | ≤ 50 ms |
| Decision window for Δt evaluation | first-locked + 10 ms = ≤ 60 ms |
| Cutter fire on jettison | + 5 ms (electrical), + 10 ms (LSC propagation) |
| Wing departs | + 30 ms (mechanical separation) |
| Reserve drogue extracted | + 200 ms (AAD or pilot) |
| Reserve canopy inflated | + 1.5–3 s |

The detection-to-jettison-fire path has to complete in **under 75 ms** to
ensure the wing is clear before reserve deployment begins, even if the
pilot starts the reserve immediately on noticing the failure.

## Pre-mitigation likelihood

From `analysis/deployment/symmetry-budget.md` (50 k-trial Monte Carlo over
the locked architecture's 5 contributors): combined 3-σ |Δt| = 16.3 ms vs
the 10 ms gate. False-positive jettison rate at the 10 ms gate: ~25 %.

That's not the failure rate; that's the **rate at which the gate fires
for an arguably-recoverable deployment**. The real catastrophic-asymmetry
rate is dominated by extreme outliers in the same distribution — about
1 in 1,000 trials show |Δt| > 18 ms, where the wing is fully open on
one side but the other isn't, and the roll impulse is severe.

## Mitigation — the architecture amendment

The nominal jettison path (Δt > 10 ms → fire all 4 cutters → wing
departs, reserve deploys) is *post-failure remediation*. The primary
mitigation is **preventing the asymmetry in the first place**.

Per `analysis/deployment/symmetry-budget.md`, the BRIEF architecture
(decision #5: passive sequencing through a single valve) cannot meet the
10 ms 3-σ gate. The recommended amendment is **Option B — active per-side
flow modulation**: the FCS senses per-side stage-lock progress and
modulates per-side valve flow to slow whichever side is leading, in
real-time. With Option B's modeled variance, 3-σ drops to 8.1 ms and the
catastrophic-asymmetry tail (|Δt| > 18 ms) drops by ~3 orders of
magnitude.

Option B *requires* the FCS to be in the deployment loop (vs. open-loop
sequencing). This is a real architecture change: the FCS becomes
deployment-critical, not just flight-critical. The mitigation for FCS
fault-during-deploy is unchanged — fire jettison, reserve.

## Response

```
asymmetric deploy detected
        │
        ├──► fire all 4 spar-root cutters (LSC, dual initiators per cutter)
        │
        ├──► wing assembly departs in < 50 ms
        │
        ├──► reserve canopy command issued (or AAD-initiated)
        │
        └──► pilot canopy descent and landing as a normal skydive scenario
```

After jettison, the underlying piggyback skydiving rig functions normally
(reserve canopy inflates clean over the head — verified geometrically in
`safety/reserve-compat.md`). The pilot lands under the reserve canopy.

## Residual risk

After mitigation:

- **Catastrophic asymmetry that escapes detection:** requires both the
  spar-lock channel AND the roll-rate channel to fail to detect. With
  redundant sensors and independent logic paths, residual probability is
  estimated < 10⁻⁵ per deploy. Acceptable.
- **Cutter no-fire on one or more cutters:** if 2 of 4 fail to fire,
  partial separation could foul the reserve. Residual risk addressed in
  `safety/failure-modes/cutter-no-fire.md` (TBD) — dual initiators per
  cutter and B-basis no-fire/all-fire margins on the LSC are the
  mitigations.
- **Reserve fouling on residual structure:** geometric clearance verified
  in `safety/reserve-compat.md` (TBD content); also a verification gate
  on the drop article (`test/drop/`).

## Verification gates

The following must be measured / demonstrated before manned-deployment
flight is permitted:

1. **Ground-rig 200-cycle gate** ([`test/ground/spec.md`](../../test/ground/spec.md)): demonstrates that
   the implemented architecture (Option B + the bench-tightened input
   distributions) actually closes the 10 ms 3-σ gate over the full thermal
   and humidity envelope, in 200 cycles without intervention.
2. **Lock-sensor latency** ≤ 1 ms hardware-verified per channel before
   that channel is used in the deploy gate logic.
3. **Cutter no-fire/all-fire margins** demonstrated per cutter at LSC
   acceptance test, plus dual-initiator independence verification.
4. **Drop-article asymmetric-deploy demonstration**: a deliberately
   asymmetric deploy (one side delayed) is induced and the jettison +
   reserve sequence completes cleanly on an instrumented ballast article
   ([`test/drop/`](../../test/drop/)).
5. **Reserve-canopy clearance** with severed-state stub geometry — both
   geometric (CAD) and physical (drop-article) verification.

Until **all five gates** are passed, the residual-risk numbers above are
predictions, not measurements, and manned-deployment flight is not
authorized.

## Open issues

- The roll-rate threshold (1.5 rad/s) is an engineering placeholder; once
  6DOF closed-loop simulation is in place, calibrate against the actual
  asymmetric-deploy roll profile.
- The 200 ms deployment-monitoring window is also a placeholder — it
  should be set to (longest-credible-deploy-time + 50 ms margin) once
  bench data tightens that distribution.
- Cross-coupling of asymmetric-deploy roll impulse into the bending
  load case for the slow-side spar root is not yet sized. The current
  `analysis/struct/spar_bending.py` uses symmetric loading; an asymmetric
  case at the worst credible Δt would be a load-case addition.

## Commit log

2026-05-07 chore: scaffold repo per BRIEF
    Lay out the directory tree from BRIEF.md with placeholder READMEs
    and stub design docs so subsequent analysis work has a home.
    - BRIEF.md committed verbatim (single source of truth)
    - README.md upgraded from stub to project map
    - docs/00..06 stubs covering rationale → aero → structure →
    deployment → FCS → emergency → test plan
    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
2026-05-07 aero: planform geometry + airfoil polar + Weissinger lifting-line
    First half of deliverable #1. Provides the algebra and a self-contained
    Python solver that the trim, glide-polar, and CAD pipelines can build on
    without depending on AVL/XFOIL being installed.
    planform/
    geometry.py single source of truth: chords, MAC, sweep at any chord
    fraction, wetted area, twist distribution, helpers used
    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
    [alpha_sweep.csv, span_loading.csv]
2026-05-07 aero: close deliverable #1 — CD0, trim, glide polar, AVL deck, wing CAD, doc
    Completes deliverable #1 per BRIEF: aero sizing, with the supporting
    analysis pipeline runnable end-to-end via `make aero` + `make cad`.
    avl/
    manta.avl full geometry deck for AVL verification (root + mid
    + tip sections, mirrored half-wing, MH 78 reference)
    manta.mass placeholder mass case for stability/eigenvalue
    run.sh driver for trim + alpha sweep + stability output
    README.md verification gates (CL_α ±5 %, NP ±0.05 MAC, e physical)
    lift_drag/
    cd0.py component build-up: wing skin friction (Cf mixed
    laminar/t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
    [best_glide.csv, washout_sweep.csv, wing.step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]
2026-05-08 struct: close deliverables #2 + #3 — mass budget + spar bending
    Bending analysis surfaces a finding worth knowing: the BRIEF spar
    dimensions (40 mm OD / 2 mm wall front) fail the 3 g limit case by a
    factor of ~3 in stress. Walls alone don't fix it; OD has to grow
    (I scales with D³ for thin tubes). Smallest front spar that closes the
    case at SF_strength ≥ 1.5 is 73 / 51 / 25 mm, 2.5 mm wall — adds
    +1.10 kg/side over BRIEF.
    That makes the 15.5 kg wing-mass target unreachable: total budget with
    the bending-correct spar is 16.62 kg (sweep range 16.13–17.11 kg
    across the rib-count and skin-density brackets). Doc #2 lays out
    three resolution paths: adopt the sized spar + revise budget,
    r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
    [bending_full.csv, budget_default.csv, budget_sized_spar.csv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]
2026-05-08 deploy: close deliverables #4-#6 — sequence, symmetry budget, ground rig
    #4 — Deployment sequence (the safety-case document)
    docs/03-deployment-sequence.md replaces stub. State machine,
    sensed gates, abort paths, sensor
    list, phase budgets.
    analysis/deployment/state_machine.py
    runnable IntEnum-based state machine
    with parallel abort monitors. Nominal
    exit-to-glide ≈ 5 s.
    analysis/deployment/tests/ 7 scenarios — nominal, pilot abort,
    AAD, drogue mal, asym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
    [front_fitting_cutter.step, front_fitting_cutter.stl, full_set.step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]
2026-05-08 fcs: longitudinal dynamics + alpha-limiter prototype + closed-loop sim
    #28 Longitudinal dynamics
    analysis/flightdynamics/longitudinal.py
    Linearized longitudinal state-space from upstream Weissinger +
    CD0 build-up. Eigenvalues at trim, mode classification, CG-offset
    sweep. Confirms BRIEF unsolved-problem #2: a 50 mm pilot upper-
    body shift = ±3.26 % of MAC vehicle CG shift, comparable to the
    full static margin. Alpha limiter is mandatory.
    Trim point V=20 m/s, α=7.98°, SM=5.40 % MAC, ω_n=5.97 rad/s,
    ζ=0.97 (heavily damped). Below SM=2 % the short-period
    overdamps; below 0 % the system is divergent.
    #29 Alpha limiter prototype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
    [cg_sweep.csv, scenario_cg_shift_50mm.csv, scenario_combined_overcmd_cg.csv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]
2026-05-08 safety: docs 05 + 06, FMEA matrix, asymmetric-deploy + reserve-compat
    #32 Asymmetric-deployment failure mode write-up
    safety/failure-modes/asymmetric-deployment.md
    The dominant unrecoverable case per BRIEF, written up at the
    per-failure-mode level the safety case turns on. Detection
    (per-side spar-lock Δt + roll-rate divergence), time budget
    (detect-to-jettison < 75 ms), pre/post-mitigation likelihoods,
    cascade chain to FM-RSV-001, verification gates.
    #33 Reserve compatibility analysis
    safety/reserve-compat.md
    Replaces stub. Pre-jettison harness constraints (handle reach,
    reserve PC routing, AAD access), jettison-stub geometry
    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
2026-05-08 fdyn + cad + safety: lateral dynamics, harness CAD, ribs CAD, two more failure-mode write-ups
    #38 Lateral-directional flight dynamics
    analysis/flightdynamics/lateral.py
    Roskam-tabulated stability derivatives for the swept tailless
    wing; 4-state lateral state-space; dutch-roll, roll, spiral
    mode identification; handling-quality assessment per
    MIL-F-8785 / FAR 23.142 levels.
    Findings (V = 16, 20, 25 m/s):
    - Dutch roll ζ ≈ 0.26–0.29 (Level 2 — acceptable but light;
    yaw damper recommended)
    - Roll mode τ ≈ 40–65 ms (crisp; no concerns)
    - Spiral mode DIVERGENT at low speed: time-to-double 15 s
    at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
    [integration.step, integration.stl, integration_with_cone.step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]
2026-05-08 site: Astro + Tailwind landing page that ties everything together
    Single-page static site at site/, deployable to any static host
    (Cloudflare Pages, Vercel, GitHub Pages). Built end-to-end:
    - Hero with the wing top-view rendering and a one-paragraph elevator
    - 12 metric cards covering the headline numbers across all
    deliverables, with tone coding (warn for the three architecture-
    revision findings; good for the test count)
    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
2026-05-08 drogue + pneumatics + 5 FMEA per-mode write-ups
    Real engineering finding from the drogue work: peak bridle snatch
    ≈ 3.94 kN (3.83 g) — between 3 g flight limit and 4.5 g ultimate. The
    HARNESS MOUNT must be sized to the drogue case, not 3 g flight. The
    spar roots don't see this load directly in nominal sequence (drogue
    attaches to harness, not spars), but an asymmetric-deploy event with
    drogue still attached can transmit drogue tension to the spars for
    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
    [drogue_descent.csv, option_a.step, option_a.stl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]
2026-05-08 finish out: 3 remaining FMEA, CI, bench plan, pilot training, FCS bay, site refresh
    #53 Three remaining FMEA per-mode write-ups
    safety/failure-modes/reserve-fouling.md (FM-RSV-001)
    safety/failure-modes/co2-cold-underpressure.md (FM-CO2-001)
    safety/failure-modes/reversion-fault.md (FM-RVR-001)
    FMEA per-mode coverage now: 11 / 14 → 11 / 11 (the umbrella row
    FM-SEN-001 covers 11 sensor sub-IDs in one file). The safety case
    is now fully populated at the per-mode-write-up level.
    #54 GitHub Actions CI workflow
    .github/workflows/ci.yml
    analysis-tests job: pytest + reproduce every analysis pipeline
    end-to-end + build every CAD subsyste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
    [fcs_bay.step, fcs_bay.stl, fcs_with_sensors.step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]
2026-05-08 site: deploy live to https://manta-ten.vercel.app + GH Actions auto-deploy
    #60 Vercel deploy
    - Site live at https://manta-ten.vercel.app (production alias)
    - Linked to xaxis-projects/manta on Vercel
    - vercel.json: framework=astro, bun install + build, immutable
    cache-control on /img/* assets
    .github/workflows/deploy.yml — auto-deploy to production on every
    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
2026-05-08 fix: spars now sweep with the wing; integrated assembly explains affixation
    Caught a real geometric bug: cad/spars/build.py was placing the front
    and rear spars at constant x in WORLD frame (x = 0.20·c_root and
    x = 0.65·c_root respectively, axis along +y). On a swept wing, that
    puts the spars OUTSIDE the wing OML before they reach the tip — the
    wing's LE at the tip is at x = 1.725 m, the chord is 0.649 m, so the
    wing extends from x=1.725 to x=2.374 at the tip, but the old front
    spar was still at x=0.324. The spars literally exited the wing at
    roughly mid-span.
    Also: there was no integrated assembly explaining how the wing
    attaches to the pilot. Pilot+rig CAD existed in cad/harness/, win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
    [full_assembly.step, full_assembly.stl, full_assembly_with_cone.step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]
2026-05-08 viewer: interactive 3D + animated deployment scrubber on the live site
    #63 Three.js / R3F viewer in the site
    site/src/components/viewer/Viewer.tsx
    Per-subsystem STLs loaded separately so each part can be
    colored and animated independently:
    pilot — tan opaque torso volume
    rig_main — dark gray opaque container
    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
    [front_spar.step, front_spar.stl, full_assembly.step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]
2026-05-08 stowed CAD + thickness verification — surfaces 4th architecture finding
    #64 Stowed configuration model
    cad/stowed/build.py
    Wing collapsed against pilot's body: spars retracted to root-stage
    length, lying along +x body axis on top of the sub-frame, with
    9 rib coils per side stacked along each spar. Skin gathered between
    coils (modeled as 5 mm radial allowance).
    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
    [full.stl, pilot.stl, rig_main.stl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]
2026-05-08 findings: surface the 4th architecture-revision finding
    Stowed-package thickness (267 mm) exceeds BRIEF 150 mm target — added
    to README and the site landing page alongside V_bg / sized-spar /
    active-flow-modulation findings. Findings grid widens from 3 to 4
    columns. Architecture-amendment intro updates to "deliverables #1-#6
    plus stowed-configuration verification".
2026-05-08 v2: wingsuit-extension architecture — full rebuild
    The prior architecture (aircraft-on-pilot's-back, pyrotechnic spar-root
    cutters, wing-package-stack) was wrong. The actual concept is the pilot
    wearing a wingsuit-derivative harness with an integrated CFRP spine yoke,
    arm-aligned LE spars hinged at the shoulders, telescoping wrist tip
    extensions, and a body-mounted TE spar. This commit rebuilds CAD, viewer,
    BRIEF, and README around the corrected architecture.
    DELETED (wrong architecture)
    cad/wing/ — old swept-wing-on-pilot
    cad/spars/ — old aircraft-style spars from sub-frame to tip
    cad/ribs/ — rib coils for the old architecture
    cad/harness/ — ol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
    [fcs_bay.step, fcs_bay.stl, fcs_with_sensors.step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]
2026-05-08 sim: real MuJoCo physics + Blender renders + GLB viewer
    Replaces the matplotlib stick-figure renders and STL slider with a
    proper physics-simulated deployment, Blender Eevee renders, and a
    GLB-based web viewer.
    WHAT ACTUALLY WORKS NOW
    sim/deployment_mjcf.xml
    MuJoCo MJCF model: pilot torso (welded), shoulder/elbow/wrist
    hinges, hip/knee hinges, 3-stage telescoping wrist tip extensions
    on slide joints with position controllers, body-mounted TE spar
    with 3-stage telescoping. PD controllers drive arm/leg spread
    (Phase A) and CO₂-equivalent telescoping fire (Phase B).
    sim/run_deployment.py
    Runs the forward simulation at 0.5 ms timestep, captures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
    [deployment_mjcf.xml]
2026-05-29 sim v3: organic humanoid via Skin modifier + airfoil-lofted wing
    Replaces the stick-figure stuff. New pipeline:
    sim/build.py single comprehensive script
    (1) MuJoCo MJCF model + forward simulation of the deployment
    kinematics (arm-spread + telescoping fire)
    (2) Blender scene generation:
    - Humanoid via vertex skeleton + Skin modifier + Subsurf:
    smooth organic shape with proper proportions, scaled
    per-joint via per-vertex skin radii (head, torso, limbs
    all taper realistically)
    - Telescoping tip extensions as world-space tubes between
    consecutive body positions from the simulation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
    [deployment_mjcf.xml, forearm_left.stl, forearm_right.stl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]
2026-05-29 sim: real flight physics + continuous morph-target deployment animation
    The previous sim was a marionette: MuJoCo with gravity=0, the torso pinned
    to the origin, zero aerodynamics, and a "deployment animation" that was a
    3-pose opacity crossfade (GLBs with 0 animation tracks). Rebuilt both layers.
    Physics (sim/aero.py, sim/flight_dynamics.py)
    - Aerodynamic model derived from the locked planform (S=8.4, AR=6.5,
    e=0.85, CD0=0.025) — coefficients interpolated stowed->deployed by
    deploy progress. Reproduces every BRIEF target from first principles:
    V_bg 17.0 m/s, L/D 13.2, stall 12.6 m/s, terminal 43.9 m/s (asserted
    on every run).
    - Six-state longitudinal sim of the full s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
2026-05-30 sim: fixed-proportion pilot — stop contorting the human; booms make the span
    Core architecture correction. The pilot was being stretched to the wingspan:
    the arm grew from ~4 cm (stowed) to ~86 cm (deployed) and the torso lengthened
    as the chord opened — the human was a rubber sheet pulled to 7.4 m.
    Now the pilot is a FIXED-proportion, rigid-size human (NASA-STD-3000 / ANSUR II
    segment lengths) that never stretches:
    - _pilot_fk() runs forward kinematics: limbs ROTATE about the shoulder/hip with
    CONSTANT bone lengths (upper arm 0.32, forearm 0.27, thigh 0.43, shank 0.42 m).
    Verified constant across all 60 frames (t=0..0.6).
    - The 7.4 m span beyond the pilot's ~0.76 m wrist reach is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
2026-05-30 sim: add the leg-wing TAIL + broad-shouldered torso + readable pilot
    Addresses the adversarial-review findings on the fixed-proportion rebuild:
    - LEGS-AS-TAIL (was failing): add a cambered tail membrane webbed between the
    two legs (crotch -> between the feet), behind the main wing's centre TE — the
    empennage the legs control for pitch. New 'tail' material slot, lighter tint
    so it reads as a distinct softer rear surface.
    - Torso: broad-shouldered swimmer's-V (41 cm biacromial at the shoulders ->
    28 cm waist -> 33 cm pelvis) instead of a barrel; matches the arm anchors so
    no floating-shoulder gap. Deltoid bulges bridge torso->arm.
    - Pilot reads as human: split the head into its ow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
2026-05-30 resize wing to 6.3 m / 6.5 m² (Option B) — lands under reserve, smaller is better
    Per design decision: MANTA lands under a reserve canopy, so a low stall speed
    isn't required — that frees the wing to shrink, which makes the telescoping
    boom far more feasible and the rigid wing more controllable, for almost no
    glide cost.
    - Planform: S 8.4 -> 6.5 m², b 7.4 -> 6.3 m, AR 6.5 -> 6.1 (taper 0.4, sweep
    25°, washout 6°). Updated the single source of truth (geometry.py) so all
    downstream aero recomputes.
    - Re-ran the aero suite for the new planform: CL_α 4.17 /rad, NP 0.886·MAC,
    static margin ~5.6%, V_bg 18.3 m/s, L/D 11.6 (was 16 m/s / 12.0). Telescoping
    boom drops ~2.9 -> ~2.4 m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
    [alpha_sweep.csv, best_glide.csv, span_loading.csv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]
2026-05-30 sim+site: flight-control demo — how the pilot flies it (+ pilot-in-airfoil fix)
    Builds the control kinematics/physics the user asked for, and fixes the HIGH
    issues from the state review.
    Control system:
    - A second morph pass (build_control_frames): the deployed wing performs a roll
    reversal + pitch flare. Each frame deflects the flaperons (differential for
    roll, symmetric for pitch) and weight-shifts the pilot; the bank/pitch
    attitude + load factor n=1/cos(phi) come from the documented stability/control
    derivatives (analysis/flightdynamics, docs/04) and are written to control.json.
    - Viewer: a "Fly it (control)" mode plays the control pass, banks/pitches the
    craft from control.j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
2026-05-30 sim+site: make it actually FLYABLE — interactive flight sim in the browser
    Replaces the scripted control demo with a real pilot-in-the-loop simulator.
    - Control-basis morph targets: four poses (ctrl_rollL/R, ctrl_pitchU/D) baked
    as deltas from the deployed wing (base + (pose - deployed)), so the viewer
    blends them by live input -> flaperons deflect + pilot weight-shifts in real
    time. Cuts the GLB to 4.85 MB (was 7) since the canned frames are gone.
    - control.json now carries the FLIGHT MODEL (resized-planform aero + documented
    stability/control derivatives): S, AR, CL_alpha 4.17, CD0, e, mass,
    alpha0/trim/limit/stall, V_trim, roll-rate, bank limit.
    - Viewer "Fly it": integrates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
2026-05-30 site: fly it over real terrain + sky — flight environment for the sim
    The flight sim now flies through a world instead of a void:
    - Procedural terrain (FBM heightfield, elevation-shaded brown→green→rock→snow),
    with the craft TRANSLATING through it (world x/z + altitude from the EOM) and
    banking into turns; ground contact relaunches.
    - drei Sky (sun) + drifting Clouds + distance fog for depth.
    - Camera follows the moving craft (OrbitControls target tracks it; you can still
    orbit/zoom). Near/far + sky distance bracketed so the sky dome renders.
    - HUD adds altitude; the craft glides down toward the hills.
    Inspection mode (deploy/flow) keeps the studio grid + dark backdrop.
    Co-Aut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
2026-05-30 site: proper chase camera in fly mode (was not tracking)
    OrbitControls' internal per-frame update() fought the target-follow, and a
    world-fixed offset didn't stay behind a turning craft. Replaced it:
    - OrbitControls now renders only for inspection (not while flying).
    - Flight uses a dedicated chase camera: a heading-relative offset (behind +
    above the craft), smooth time-constant follow (tau 0.18 s), looking at the
    craft — so it stays locked behind through turns and translation.
2026-05-30 sim+site: real deploy mechanism — spars along the limbs, booms from the hubs
    Fixes the structure piercing the body + shows the actual deploy mechanics.
    - CFRP structure rerouted to the real load path (BRIEF #2): the LE spar is
    bonded along the UNDERSIDE of the arm to a WRIST HUB; a 3-stage CFRP boom
    telescopes out of that hub to the wingtip (retracted/nested at the wrist in
    Phase A, extends as the span grows in Phase B). Mirror along the leg → ankle
    hub → TE boom. Everything sits just under the limb, inside the fabric, so it
    no longer pierces the body.
    - Added wrist/ankle hubs, shoulder/hip hinge knuckles, and cuffs that strap the
    arm/leg to the spar. Raised the reserve so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
2026-05-30 analysis: re-validate struct + flight-dynamics + FCS at the resized wing
    The 6.5 m²/6.3 m resize only had the AERO re-run; the structural, flight-
    dynamics, deployment and FCS analyses still carried the old 8.4 m² loads.
    Re-ran the whole suite (they import the planform from geometry.py) + fixed the
    one hardcode (alpha_limiter S/CL_alpha). All 27 tests pass.
    Real finding — the resize COSTS STABILITY (BRIEF finding #6):
    - static margin 5.4% -> 4.8% MAC (trim, 6° washout; dynamic CG-sweep tighter ~2.7%)
    - Dutch-roll damping ζ 0.29 -> 0.17 (yaw damper now mandatory, not optional)
    - spiral diverges faster; ~3 cm aft pilot CG shift takes the wing neutral
    - LE spar root 73 -> 67 mm (shorter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
    [bending_full.csv, budget_default.csv, budget_sized_spar.csv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]
2026-05-30 washout 6°→7° (recover trim margin) + docs consistency pass for the resize
    Action on BRIEF finding #6. Raised washout to 7° (geometry.py + build.py) and
    re-ran the full suite (aero/struct/FD/FCS), re-rendered the model. All 27 tests
    pass.
    Result is honest, not a free lunch:
    - TRIM static margin restored 4.8% → 5.6% MAC, tip-stall margin healthy (~10°).
    - But the BINDING (CG-based) static margin stays ~2.7% MAC — it's washout-
    INDEPENDENT (set by NP vs actual pilot CG). Genuinely recovering it needs a
    CG shift (wing aft / mass fwd), flagged as open. Since the design is FBW by
    intent, ~2.7% is FCS-managed: alpha-limiter + yaw damper now mandatory.
    Docs consistency (the gap I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
    [alpha_sweep.csv, bending_full.csv, span_loading.csv]
2026-05-30 fix top review findings: boom-piercing, inverted bank, reserve-as-head, stale aero
    From the full-state adversarial review. High-severity fixes:
    DEPLOY / PIERCING (the recurring complaint):
    - Telescoping booms now INTERPOLATE from the wrist/ankle hub to the planform
    tip by prog["tip"] — retracted = a stub AT the hub, so they never jump across
    the body to a collapsed planform point. Kills the diagonal struts that crossed
    the torso in stowed/mid (LE climb + TE forward-sweep both gone).
    - Reserve shrunk, dropped low + behind the shoulders, desaturated to a dark
    pack colour — it was the tallest/brightest element and read as the head.
    Now the helmet reads as the head. Cuffs narrowed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
    [best_glide.csv]
2026-06-04 deploy: real bistable rib coil-unroll + strain-energy physics ROM
    Replace the placeholder thickness-lerp rib with the actual deployment
    mechanism the BRIEF specifies: 9 bistable rolled-composite tape-spring
    ribs/side that unroll from a packed coil at the LE spar hub onto the
    airfoil and self-latch. Couple the geometry to integrated physics so the
    animation is physics-driven, not an ad-hoc ease.
    sim/build.py
    - Mesh.rib_unroll: continuous coil->airfoil geometry (deployed part lays
    on the airfoil front->hub; wound part is an Archimedean spiral at the
    hub; they meet at chord0/arc0). Fixed topology (2*N_RIB_STN verts) for
    clean morphing. Verified: f=0 -> 3.2cm coil, f=1 -> full airfoil rib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
2026-06-04 fix: enclose the pilot in a worn-suit center-body — head no longer pierces the wing
    The pilot's head pierced UP through the wing skin (~9 cm) and the body read as
    a bare human jammed into a separate wing. Root cause: a human does not fit
    inside a 12% airfoil (max half-thickness 0.088 m vs torso half-depth 0.118 m +
    head), and the head was deliberately raised +0.11 m to "breach the canopy".
    Rebuilt around a blended center-body / worn-wingsuit architecture:
    - center_fair(): the wing centre lifts into a canopy over the head + dorsal hump
    over the back, and a belly pod under the chest, fairing to the clean airfoil by
    FAIR_Y_OUT and SEALED to zero within 5% chord of LE/TE so the airfoil st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
2026-06-04 deploy: membrane form-finding → smooth controlled surface; regenerate ALL site images
    Two fixes.
    1) Physics of deployment into a controlled surface. MANTA is a RIGID deployable
    wing, but the skin used an ad-hoc 14% billow that read as a pillowy ram-air
    canopy. Added analysis/deployment/membrane_formfinding.py: the deployed skin is a
    PRETENSIONED membrane stretched over the bistable ribs (booms tension it spanwise,
    the rib snap chordwise). Bay sag from membrane statics δ=q·s²/(8·N), cross-checked
    by discrete relaxation. With ~2.2 kN/m pretension the worst inter-rib sag is
    ~1.9 mm even at 3 g — surface waviness 0.16–0.27% chord, inside the 0.4% aero
    tolerance, wrinkle-free. So the d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
    [membrane_sag.csv, scenario_cg_shift_50mm.csv, scenario_combined_overcmd_cg.csv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]
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2026-10-22 Build the model CI checks from the code that still exists
    CI has been red since the v2 rebuild in May. Its CAD steps ran
    cad/wing/build.py and five other cad/ scripts that v2 deleted. v3 then
    moved the whole model into sim/build.py, and CI never followed.
    The steps now run the sim pipeline and sim/build.py. The build must
    reproduce the committed GLB and its JSON exactly, so a model change that
    wasn't regenerated fails the check.
    bpy 5.0.1 is pinned because Blender 5.0 exported the committed GLB.
    It needs Python 3.11 and a few X11/GL libraries on the runner.
    cadquery goes, since nothing imports it any more. CI installs
    requirements.txt, so make venv and CI get the same packages. The
    Makefil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
